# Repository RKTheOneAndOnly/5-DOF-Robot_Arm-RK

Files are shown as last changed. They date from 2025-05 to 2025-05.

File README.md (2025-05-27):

# 🤖 Kai (ಕೈ): A 5 Degree of Freedom Robotic Arm

Welcome to **Kai (ಕೈ)** — my latest hobby project and a significant step forward in my robotics journey. Kai (ಕೈ), meaning "hand" in Kannada, is a 5-DOF robotic arm built as a natural progression from my 3DOF project. With improved dexterity, orientation control, and a modular design, this DIY robotic arm project explores robotics, control systems, and embedded programming.
<p align="center">
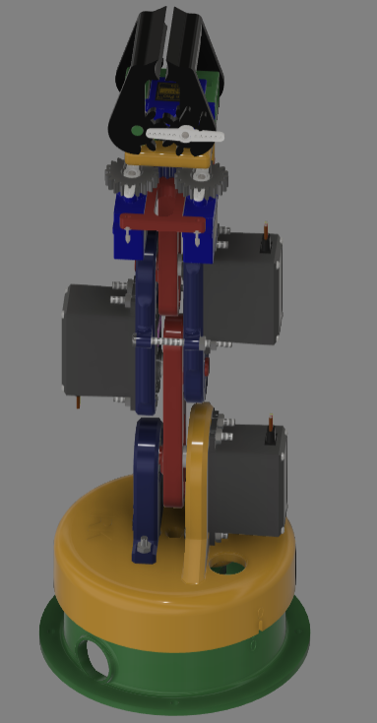
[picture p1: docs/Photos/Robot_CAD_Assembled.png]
Kai Robot CAD
    
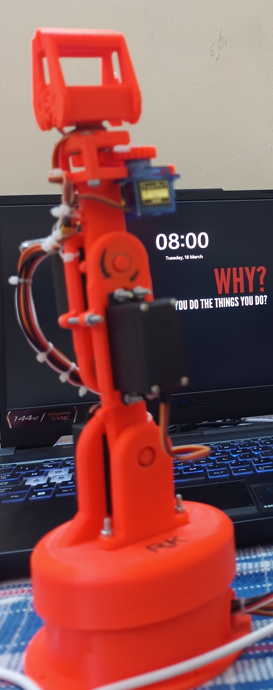
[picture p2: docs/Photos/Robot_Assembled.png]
Kai Robot Assembled
    
</p>

## 🔁 Previous Version: 3DOF Arm (V01)

Before building Kai (5DOF), I developed a 3DOF robotic arm as a foundational project. You can check it out here:

🔗 [Robotics-Arm-Project-V01](https://github.com/RKTheOneAndOnly/Robotics-Arm-Project-V01)

This earlier version helped me explore servo control, basic kinematics, and get hands-on with 3D printing and embedded design.

---
## Table of Contents

1. [Introduction](#1-introduction)
2. [Components Used](#2-components-used)
3. [Assembly Instructions](#3-assembly-instructions)
4. [Wiring Diagram](#4-wiring-diagram)
5. [Code Overview](#5-code-overview)
6. [Robot Video](#6-robot-video)
7. [Future Plans](#7-future-plans)
8. [License](#8-license)
9. [Repository Structure](#9-repository-structure)
10. [Credits & Acknowledgements](#10-credits--acknowledgements)

---
## 1. Introduction

This project focuses on designing, assembling, and controlling a 5DOF robotic arm that is:
-  Fully 3D printable
-  Made using easily available components
-  Controlled via inverse kinematics (IK) using Python + IkPy
-  Powered by ESP32 & PlatformIO, with web-based remote control
-  Open-source for learners, hobbyists, and engineers

---
## 2. Components Used

A detailed Engineering Bill of Materials (EBOM) is provided [here (Excel)](docs/Bill_of_Materials-5_DOF_Robot.xlsx).

| Component | Quantity | Notes |
|---|---|---|
| MG995  Servos | 1 | High torque servo motors |
| MG996R Servos | 4 | High torque servo motors |
| ESP 32 | 1 | Main controller |
| PCA 9685 | 1 | Servo driver (I2C) |
| 5V Power Supply  | 1 | Power source for servos |
| 3D Printed Parts | ~10 | Provided in `/stl` folder  |
| Misc. Hardware | - | Screws, bearings, etc. |

---
##  3. Assembly Instructions

The robotic arm is composed of modular, 3D-printed PLA joints designed for ease of assembly. Printing parameters such as infill density are provided in the [Bill of Materials (BOM)](docs/Bill_of_Materials-5_DOF_Robot.xlsx).

> 📌 **Note**: The part names used in these instructions match the file names available in the [STL](./stl) folder.

Follow the steps below to assemble **Kai**:

---

### 1. **Base Setup**
Mount the base servo motor (`MG995`) into the `BASE` structure. Insert ball bearings into their respective housings to reduce rotational friction. The base includes cutouts to route wires neatly and prevent tangling during rotation.

---

### 2. **Rotary Base Assembly**
Attach the `ARM-1-MAIN` component to the `BASE`. Ensure the base servo is positioned at **90°**, and align the zero markers on both `BASE` and `ARM-1-MAIN` for proper orientation.

---

### 3. **Support Arm & Second Servo Installation**
Fix the support arm `ARM-1-AUX` onto `ARM-1-MAIN` using screws. This component provides structural support via its bearing housing. Mount the second MG995 servo into `ARM-1-AUX`.

---

### 4. **Attaching the First Arm**
Connect `ARM-2` to the second servo motor (`MG996R`). Ensure the servo is set to **90°** before coupling to maintain consistent mechanical zeroing. The `ARM-2` component includes a boss feature that rides on the bearing within `ARM-1-AUX` to enhance rigidity and stability of the robot.

---

### 5. **Assembling the Second Arm**
Join `ARM-3-1` and `ARM-3-2` using two servo motors (`MG996R`) and screws. These parts include bearing housings that support both `ARM-2` and the upcoming `ARM-4` assembly. Once assembled, connect the complete second arm (`ARM-3-1` and `ARM-3-2` with servos) to `ARM-2` as shown in the reference images.

---

### 6. **Wrist Mechanism & Third Arm**
Mount `ARM-4` to the end of the second arm (`ARM-3`). Attach **two SG-90 micro servos**, which jointly drive a gear mechanism responsible for **wrist rotation (5th DOF)**. The mechanism is supported by bearings and features a square drive shaft for the gripper interface.

---

### 7. **Gripper Installation**
Fix the 3D-printed gripper to the square shaft of the wrist gear mechanism using screws. The gripper is actuated by a single `SG-90` micro servo, enabling open-close functionality. Ensure proper alignment for smooth operation.

---

### Step-by-Step Assembly Images

| Step | Image |
|---|---|
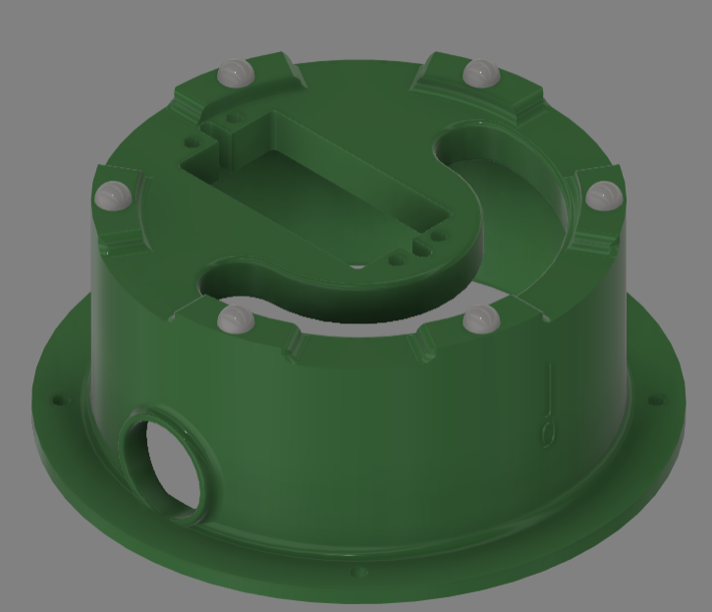
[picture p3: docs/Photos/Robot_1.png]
Base & Bearings
|1) **Base & Bearings** |  |
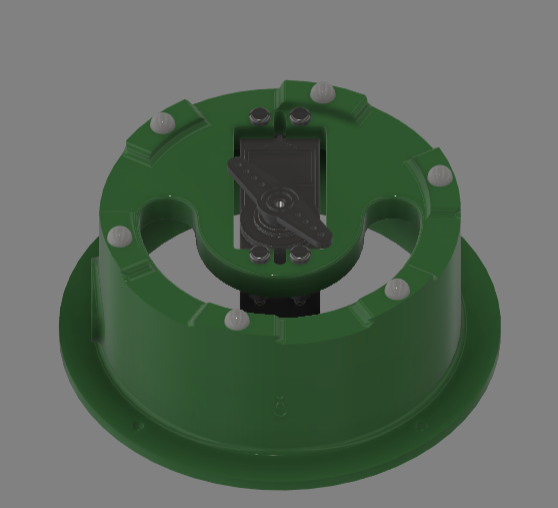
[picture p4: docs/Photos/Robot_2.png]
Base Motor Assembly
|2) **Base Motor Assembly**|  |
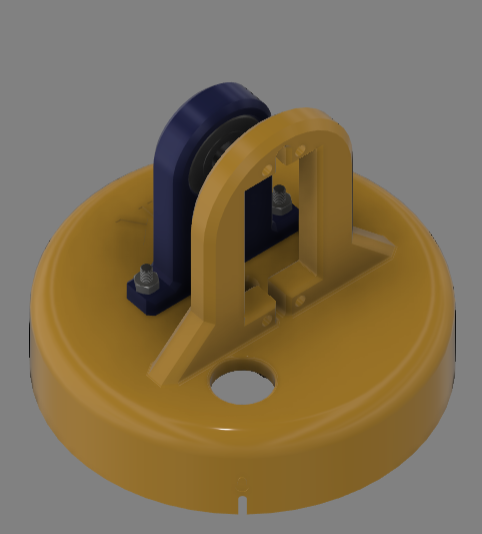
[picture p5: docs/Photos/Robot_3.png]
Arm 1 Assembly
|3) **Arm 1 Assembly** |  |
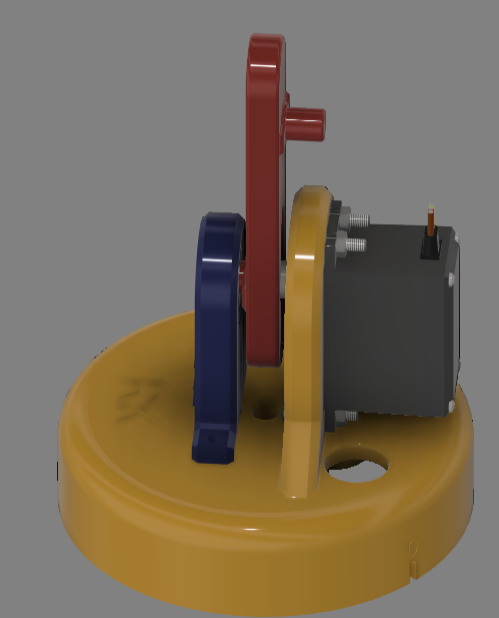
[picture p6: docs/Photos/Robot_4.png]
Arm 2 Assembly
|4) **Arm 2 Assembly** |  |
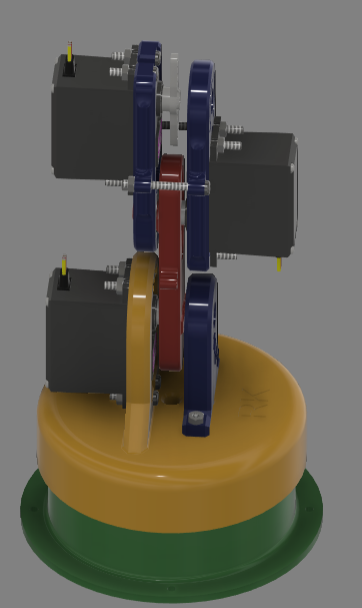
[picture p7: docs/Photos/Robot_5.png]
Arm 3 Assembly
|5) **Arm 3 Assembly** |  |
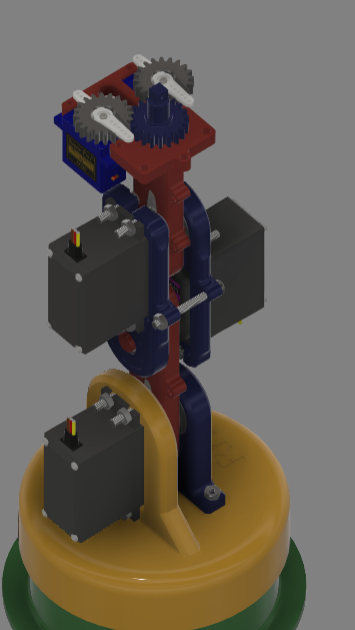
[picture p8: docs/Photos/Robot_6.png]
Wrist Gearing (a)
|6a)**Wrist Gearing (a)** |  |
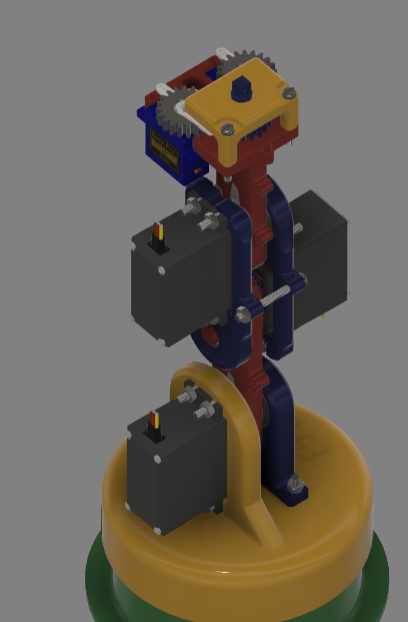
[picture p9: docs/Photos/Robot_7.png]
Wrist Gearing (b)
|6b) **Wrist Gearing (b)** |  |
|7) **Gripper & Final View** | Gripper & Final View |

> 🔧 **Tip**: Always set servos to **90°** before mechanical assembly to ensure consistent zeroing. This greatly simplifies motion planning and inverse kinematics calculations.

---

## 4. Wiring Diagram

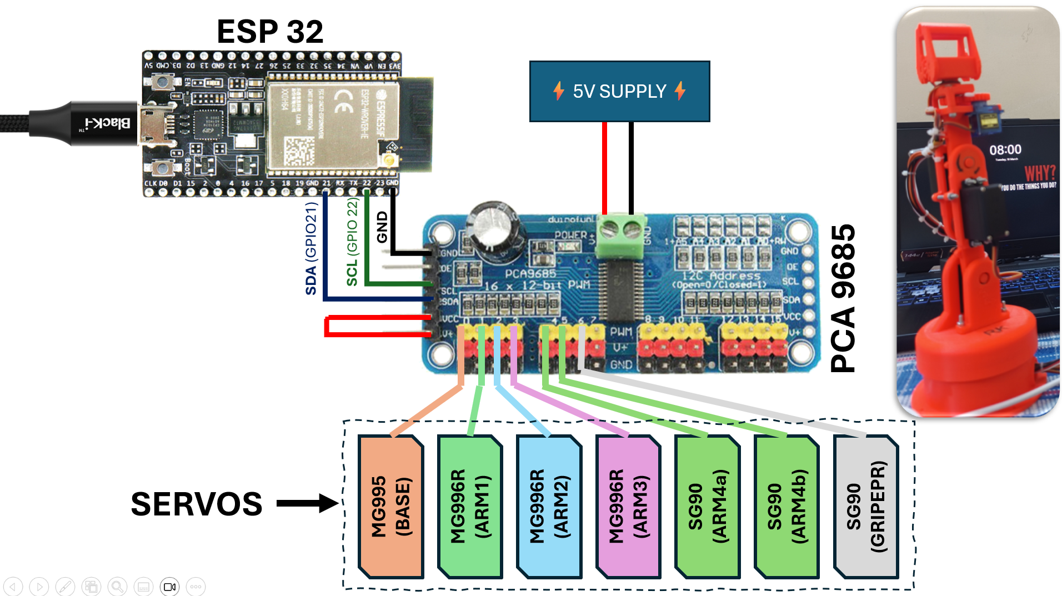
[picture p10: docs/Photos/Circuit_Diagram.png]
Wiring Diagram
  
*Wiring layout showing servo connections, PCA9685, ESP32 pinout, and external power supply.*

---

###  Key Wiring Details:

1. **Servo Connections**  
   A total of **7 servo motors** are used in this project. These are connected to a **PCA9685 16-channel PWM driver**, which is interfaced with the ESP32 via the **I2C** protocol.

2. **Microcontroller Interface**  
   The **ESP32** handles communication and control. I2C lines (SDA and SCL) from the ESP32 are connected to the corresponding inputs on the PCA9685.

3. **Power Supply**  
   An **external 5V power supply** is used to power the servos. Ensure that the **ground (GND)** of the power supply is **shared** with both the ESP32 and the PCA9685 module.

---

##  5. Code Overview

This project is powered by a combination of embedded C++ (via PlatformIO) and Python scripts, enabling high-level control, real-time kinematics solving, and remote web-based interfacing.

###  Inverse Kinematics Solver (Python)

- **Library Used**: [IkPy](https://github.com/Phylliade/ikpy)  
- **URDF Model**: The robot's kinematics are defined using a custom **URDF file**.
- **Functionality**:  
   - Accepts Cartesian goal position (x, y, z, orientation).
   - Solves inverse kinematics using the robot's URDF.
   - Outputs an array of 7 servo angles, ready to be sent to the microcontroller.

> 📁 Code Path: [`/code/src/Inverse_Kinematics_Controller.py`](./code/src/Inverse_Kinematics_Controller.py)

> 📁 URDF Path: [`/code/URDF_FIVE_DOF.urdf`](./code/URDF_FIVE_DOF.urdf)

---

### Web-based Remote Controller

The robot can be controlled manually using a web-based user interface hosted by a **Python Flask** server. This controller provides an intuitive and responsive way to articulate **Kai** in real-time without needing any complex tools.

- **Framework**: Python Flask  
- **Functionality**:
   - Hosts a local webpage with slider-based and button-based controls.
   - Sends real-time position and orientation inputs from the browser to the backend.
   - The backend converts these inputs to joint angles and sends them to the ESP32 for actuation.

> 📁 Code Path: [`/code/src/Online_Controller.py`](./code/src/Online_Controller.py)

The interface is designed to allow smooth and user-friendly manipulation of the robot. A preview of the controller is shown below:

<p align="center">
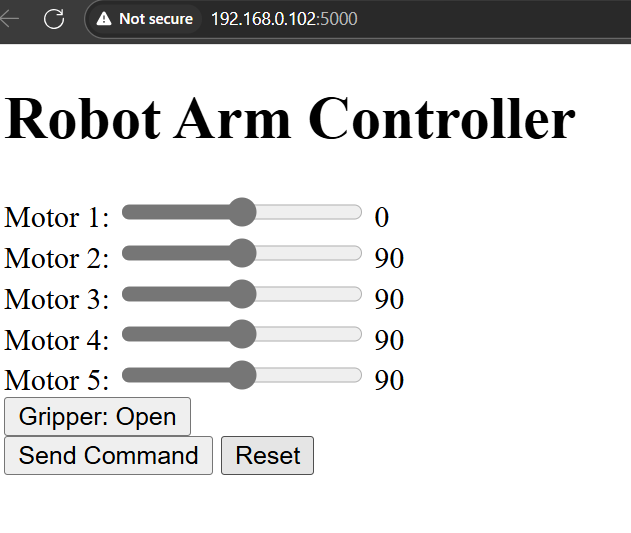
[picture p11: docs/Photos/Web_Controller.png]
Web Controller Interface
  
</p>

---
## 6. Robot Video

Here’s a glimpse of **Kai – the 5DOF Robotic Arm** in action!

The robot performs real-time pick-and-place tasks and orientation-based manipulation using servo-driven joints controlled via a inverse kinematics controller. The video showcases the robot arm demonstrating smooth motion control, coordinated joint movement, and precise end-effector positioning. 

This demonstration highlights Kai’s capabilities in workspace articulation, grip control, and stable motion handling — all built using affordable components and open-source tools.
Here are some demonstration videos of Kai (ಕೈ) in action:

> To watch demonstration videos of Kai (ಕೈ), please use the direct links below:

- [Video 1 – Orientation Control Demo](docs/Videos/Vid_1.mp4)
- [Video 2 – Pick and Place Demo](docs/Videos/Vid_2.mp4)

## 7. Future Plans

- Integrate camera for visual pick-and-place
- Full ROS2 implementation (RViz + MoveIt)

## 8. License

Licensed under the **GNU General Public License v3.0 (GPL-3.0)**.  
See the [LICENSE](./LICENSE) file for full details.

## 9. Repository Structure
```bash
5-DOF-Robotic-Arm-RK/
├── code/
│   ├── .pio/
│   ├── src/
│   │   ├── templates/
│   │   ├── Inverse_Kinematics_Controller.py
│   │   ├── Online_Controller.py
│   │   └── main.cpp
│   ├── URDF_FIVE_DOF.urdf
│   └── platformio.ini
├── docs/
│   ├── Photos/
│   ├── Videos/
│   ├── Bill_of_Materials-5_DOF_Robot.xlsx
│   └── robot_arm.yaml
├── stl/
├── LICENSE
└── README.md

```
## 10. Credits & Acknowledgements

Special thanks to:

- [IkPy](https://github.com/Phylliade/ikpy) – for providing an easy-to-use inverse kinematics library.
- [PlatformIO](https://platformio.org/) – for simplifying embedded development and dependency management.
- The open-source robotics community – for the abundance of shared knowledge, tools, and inspiration.

> *Crafted with ❤️, driven by curiosity, and fueled by innovation.*

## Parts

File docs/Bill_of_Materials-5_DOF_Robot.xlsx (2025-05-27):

Component List
Sl.No | Component | Quantity
1 | MG995 - Servo | 1
2 | MG996R - Servo | 3
3 | PCA9685 - Servo Driver I2C | 1
4 | SG 90 | 3
5 | 5V 5A SMPS Power Supply | 1
6 | M3 x 0.5 x 16 Pan Head Screw | 18
7 | M3 x 0.5 x 25 Pan Head Screw | 2
8 | M3 x 0.5 x 30 Pan Head Screw | 2
9 | M2 x 0.4 x 12 Pan Head Screw | 1
10 | Hex Nut M3 x 0.5 | 22
11 | Hex Nut M2 x 0.4 | 2
12 | Bearing 608ZZ | 4
13 | ESP 32 Dev Kit | 1
3D Printed Parts
Sl.no | Component | Infill % | Quantity
1 | BASE | 40 | 1
2 | ARM-1-MAIN | 60 | 1
3 | ARM-1-AUX | 60 | 1
4 | ARM-2 | 70 | 1
5 | ARM-3-1 | 60 | 1
6 | ARM-3-2 | 60 | 1
7 | ARM-4 | 60 | 1
8 | GEAR-SG-90-1 | 80 | 1
9 | GEAR-SG-90-2 | 80 | 1
10 | ARM-5-GEAR | 80 | 1
11 | ARM-5-HOLDER | 30 | 1
12 | GRIPPER-BASE | 70 | 1
13 | GRIPPER-ARM-LEFT | 80 | 1
14 | GRIPPER-ARM-RIGHT | 80 | 1
15 | Enclosure | 30 | 1

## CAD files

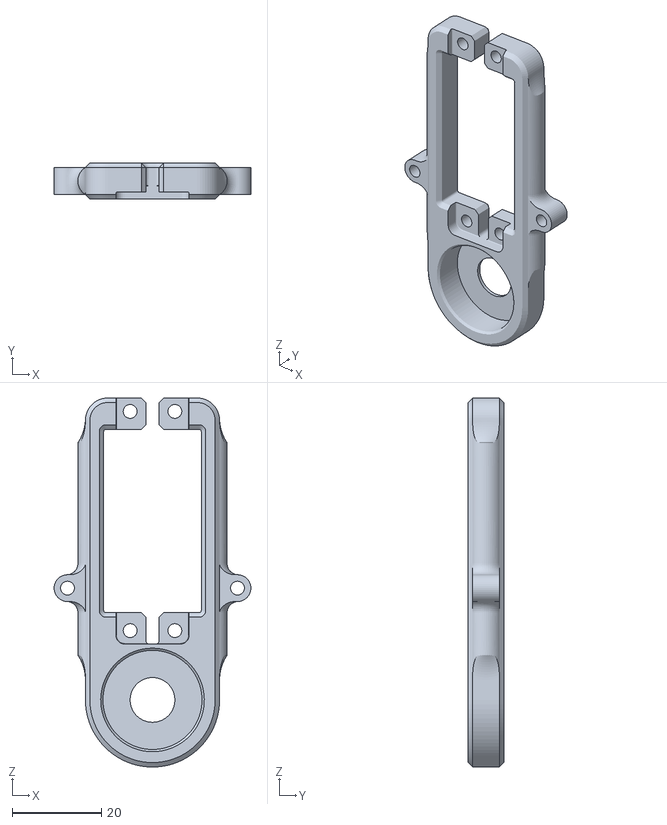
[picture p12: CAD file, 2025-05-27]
stl/ARM-3-2.stl
44.0 x 8.00 x 82.5

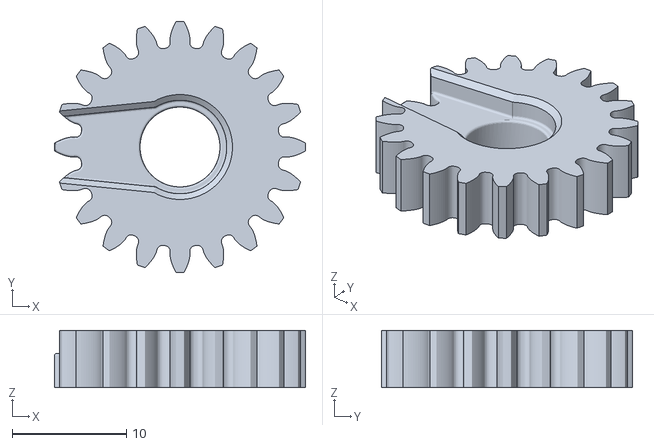
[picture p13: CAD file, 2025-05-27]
stl/GEAR-SG-90-1.stl
22.0 x 22.0 x 5.00

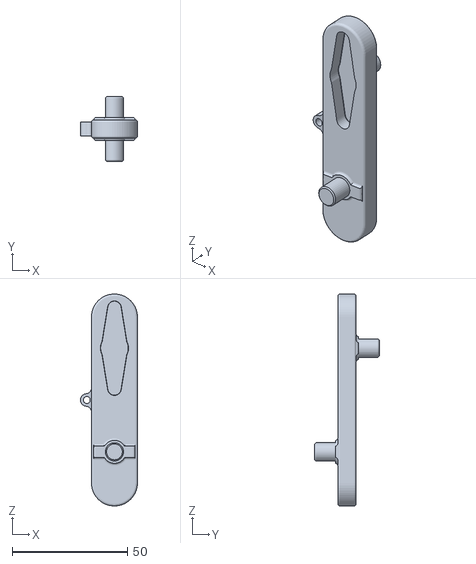
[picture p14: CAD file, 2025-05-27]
stl/ARM-2.stl
24.7 x 28.0 x 92.0

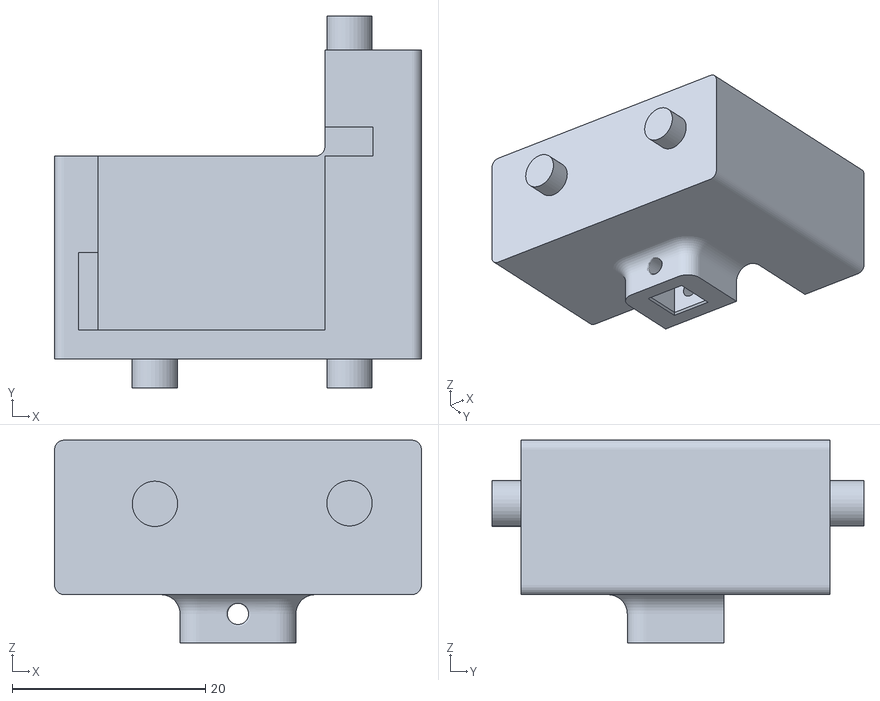
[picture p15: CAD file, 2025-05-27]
stl/GRIPPER-BASE.stl
38.0 x 38.5 x 21.0

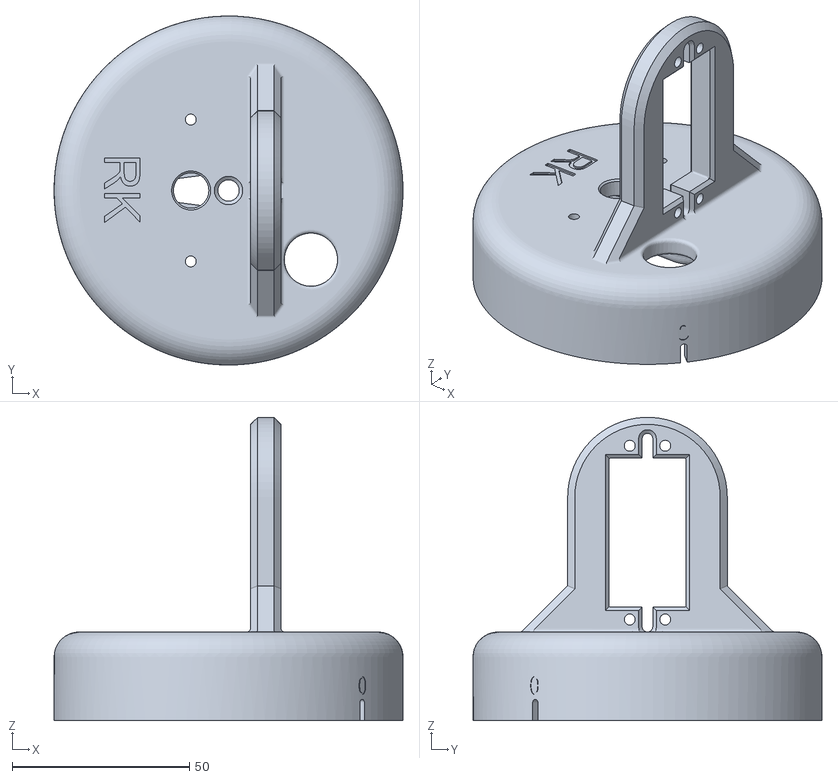
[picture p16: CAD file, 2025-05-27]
stl/ARM-1.stl
98.4 x 98.4 x 85.5

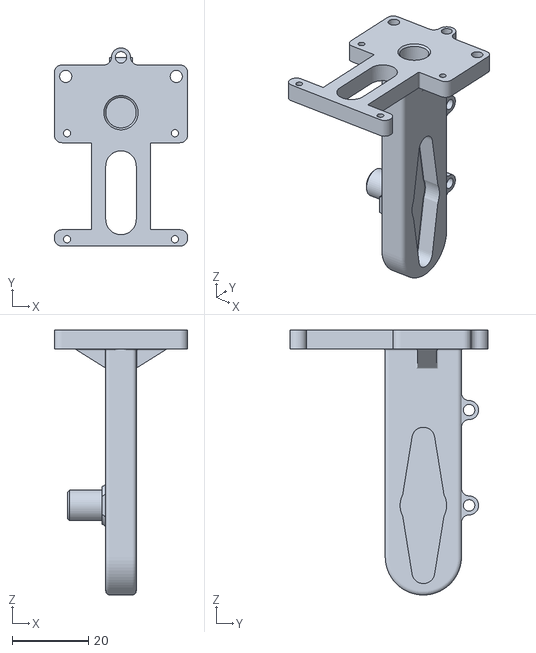
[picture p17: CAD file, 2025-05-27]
stl/ARM-4.stl
35.0 x 52.0 x 69.5

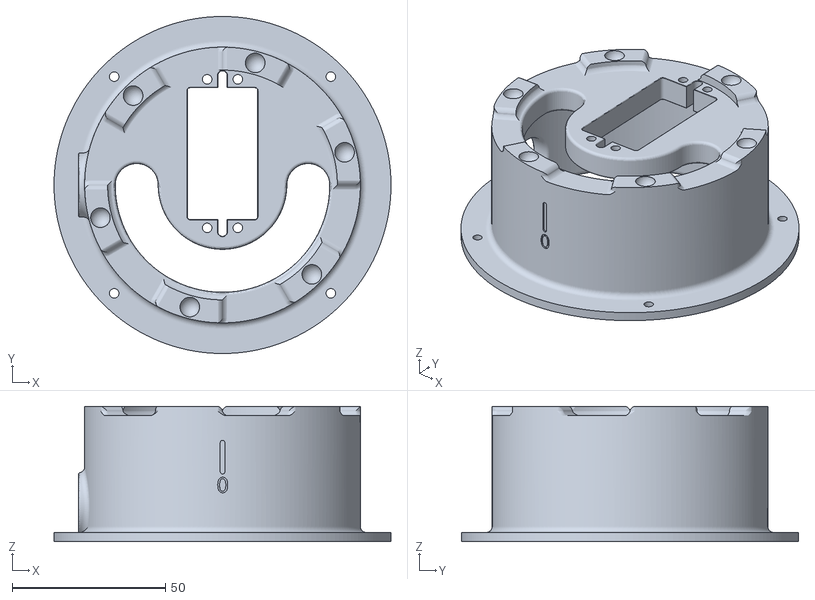
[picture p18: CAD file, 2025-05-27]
stl/BASE.stl
110.0 x 110.0 x 44.2

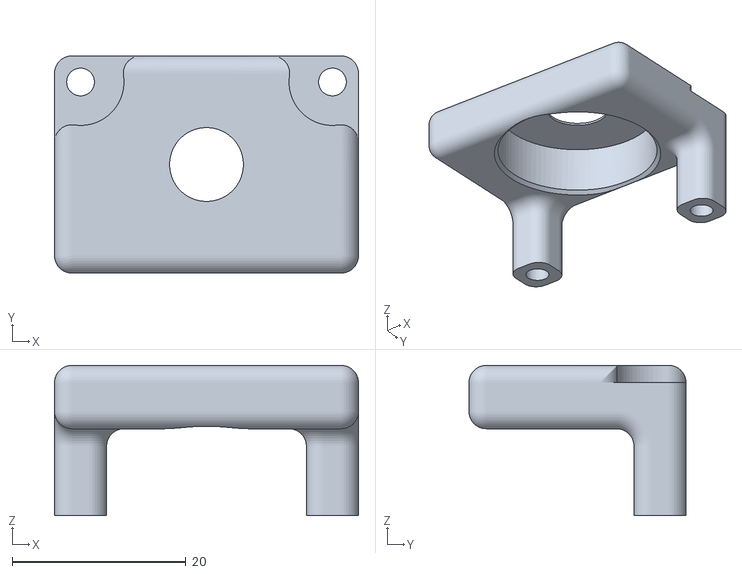
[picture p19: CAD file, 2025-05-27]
stl/ARM-5-HOLDER.stl
35.0 x 25.0 x 17.3

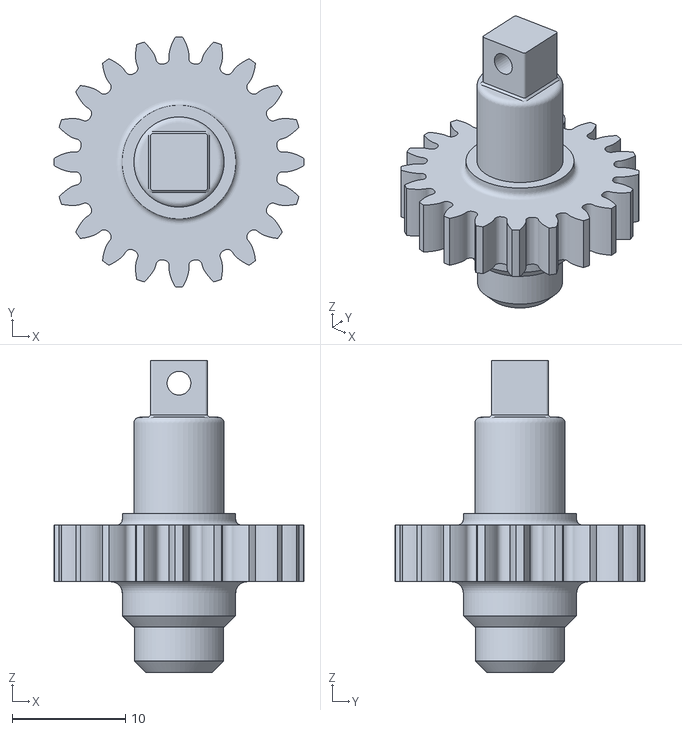
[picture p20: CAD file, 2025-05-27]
stl/ARM-5-GEAR.stl
22.0 x 22.0 x 27.5

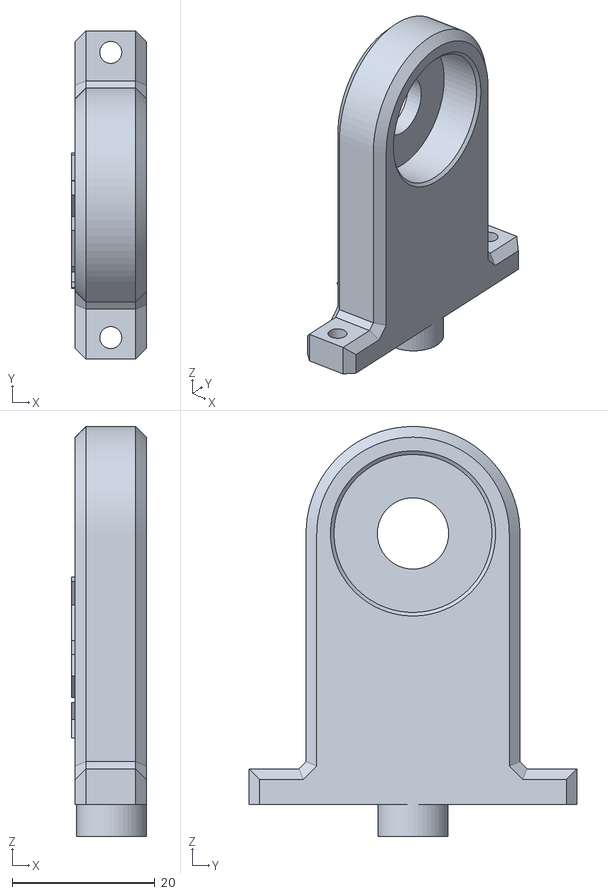
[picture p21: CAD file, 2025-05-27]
stl/ARM-1-AUX.stl
10.5 x 46.0 x 57.5

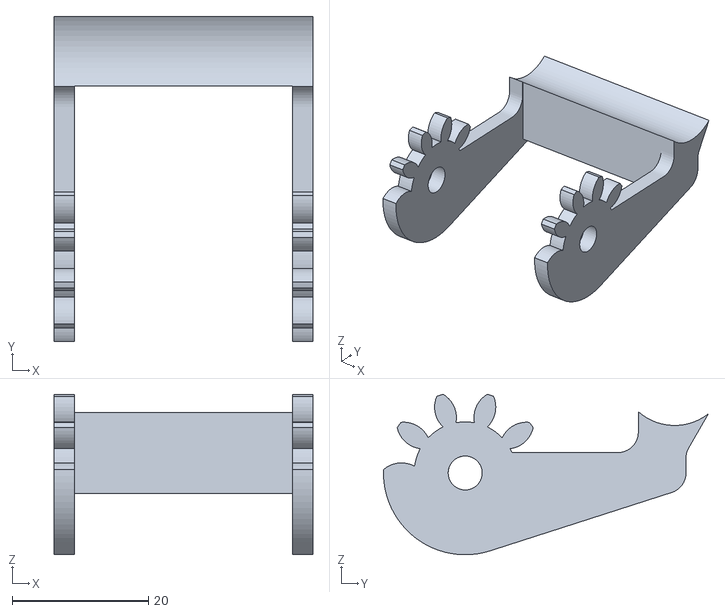
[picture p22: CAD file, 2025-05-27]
stl/GRIPPER-ARM-RIGHT.stl
38.0 x 47.7 x 23.6

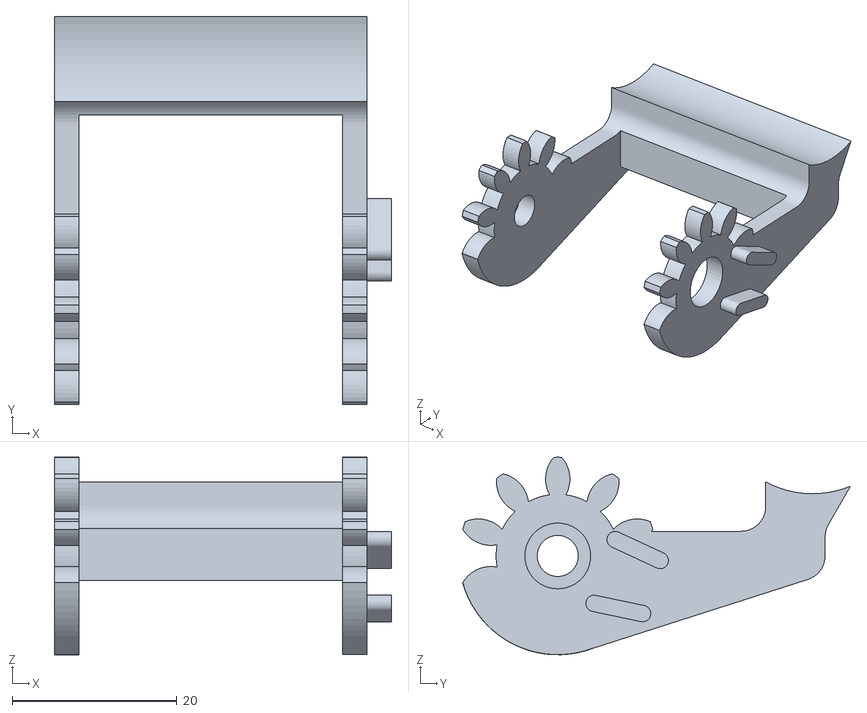
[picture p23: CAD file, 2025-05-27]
stl/GRIPPER-ARM-LEFT.stl
41.0 x 47.2 x 24.0

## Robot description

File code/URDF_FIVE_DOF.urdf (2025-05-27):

<?xml version="1.0"?>
<robot name="5DOF_Robot_By_Rohith_Kini_T">

<!-- Base Link -->
<link name="base_link">
		<visual>
		    <origin xyz="0 0 22.5" rpy="0 0 0"/>
			<geometry>
				<cylinder length="45" radius="50"/>
			</geometry>
		</visual>	
	</link>

<link name="Base_Rotary">
  <visual>
    <geometry>
      <box size="50 50 45" />
    </geometry>
  </visual>	
</link>
    
<joint name="Base_Joint" type="revolute">
  <parent link="base_link"/>
  <child link="Base_Rotary"/>
  <origin xyz="0 0 67.5" rpy="0 0 0" />
  <axis xyz="0 0 1"/>
  <limit lower="-1.571" upper="1.571"/>
</joint>

<link name="Arm1">
  <visual>
  <origin xyz="0 0 22.5" rpy="0 0 0"/>
    <geometry>
      <cylinder length="45" radius="15"/>
    </geometry>
  </visual>
</link>

<joint name="Arm1_Rotary" type="revolute">
  <parent link="Base_Rotary"/>
  <child link="Arm1"/>
  <origin xyz="0 0 22.5" rpy="0 0 0"/>
  <axis xyz="1 0 0"/>
  <limit lower="-1.571" upper="1.571"/>
</joint>

<link name="Arm2">
  <visual>
  <origin xyz="0 0 25" rpy="0 0 0"/>
    <geometry>
      <cylinder length="50" radius="10"/>
    </geometry>
  </visual>
</link>

<joint name="Arm2_Rotary" type="revolute">
  <parent link="Arm1"/>
  <child link="Arm2"/>
  <origin xyz="0 0 45" rpy="0 0 0"/>
  <axis xyz="1 0 0"/>
  <limit lower="-1.571" upper="1.571"/>
</joint>

<link name="Arm3">
  <visual>
  <origin xyz="0 0 23" rpy="0 0 0"/>
    <geometry>
      <cylinder length="46" radius="8"/>
    </geometry>
  </visual>
</link>

<joint name="Arm3_Rotary" type="revolute">
  <parent link="Arm2"/>
  <child link="Arm3"/>
  <origin xyz="0 0 50" rpy="0 0 0"/>
  <axis xyz="1 0 0"/>
  <limit lower="-1.571" upper="1.571"/>
</joint>

<link name="Arm4">
  <visual>
  <origin xyz="0 0 33.85" rpy="0 0 0"/>
    <geometry>
      <box size = "10 10 68.7"/>
    </geometry>
  </visual>
</link>

<joint name="Arm4_Rotary" type="revolute">
  <parent link="Arm3"/>
  <child link="Arm4"/>
  <origin xyz="0 0 46" rpy="0 0 0"/>
  <axis xyz="0 0 1"/>
  <limit lower="-1.571" upper="1.571"/>
</joint>

<link name="Gripper">
  <visual>
  <origin xyz="0 0 -10" rpy="0 0 0"/>
    <geometry>
      <box size = "20 20 20"/>
    </geometry>
  </visual>
</link>

<joint name ="Gripper" type="fixed">
  <parent link="Arm4"/>
  <child link="Gripper"/>
  <origin xyz="0 0 68.7" rpy="0 0 0"/>
</joint>

</robot>

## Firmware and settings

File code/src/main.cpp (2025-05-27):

#include <arduino.h>
#include <Adafruit_PWMServoDriver.h>
#include <Wire.h>
#include <SPI.h>

const int SERVO_1 = 0;  // Base Rotation
const int SERVO_2 = 1;  // Arm 1 Rotation
const int SERVO_3 = 2;  // Arm 2 Rotation
const int SERVO_4 = 3;  // Arm 3 Rotation
const int SERVO_5a = 4; // Arm 4 Rotation a
const int SERVO_5b = 5; // Arm 4 Rotation b
const int SERVO_6 = 6;  // Gripper

const int SERVO_1_MIN = 115; // Min Pulse MG 995
const int SERVO_1_MAX = 580; // Max Pulse MG 995
const int SERVO_2_MIN = 120; // Min Pulse MG 996R
const int SERVO_2_MAX = 560; // Max Pulse MG 996R 
const int SERVO_3_MIN = 120; // Min Pulse MG 996R
const int SERVO_3_MAX = 560; // Max Pulse MG 996R
const int SERVO_4_MIN = 120; // Min Pulse MG 996R
const int SERVO_4_MAX = 560; // Max Pulse MG 996R
const int SERVO_5_MIN = 100; // Min Pulse SG90 Tower Pro
const int SERVO_5_MAX = 570; // Max Pulse SG90 Tower Pro
const int SERVO_6_MIN = 100; // Min Pulse SG90 Tower Pro
const int SERVO_6_MAX = 570; // Max Pulse SG90 Tower Pro

const int SERVO_1_MIN_ANGLE = 0; // Min Anglle for Base Rotation
const int SERVO_1_MAX_ANGLE = 180; // Max Angle for Base Rotation
const int SERVO_2_MIN_ANGLE = 0; // Min Angle for Arm 1 Rotation
const int SERVO_2_MAX_ANGLE = 180; // Max Angle for Arm 1 Rotation
const int SERVO_3_MIN_ANGLE = 0; // Min Angle for Arm 2 Rotation
const int SERVO_3_MAX_ANGLE = 180; // Max Angle for Arm 2 Rotation
const int SERVO_4_MIN_ANGLE = 0; // Min Angle for Arm 3 Rotation
const int SERVO_4_MAX_ANGLE = 180; // Max Angle for Arm 3 Rotation
const int SERVO_5_MIN_ANGLE = 0; // Min Angle for Arm 4 Rotation
const int SERVO_5_MAX_ANGLE = 180; // Max Angle for Arm 4 Rotation
const int SERVO_6_MIN_ANGLE = 135; // Min Angle for Gripper
const int SERVO_6_MAX_ANGLE = 175; // Max Angle for Gripper

// Parking Positions for Servos
const int SERVO_1_PARK = 90; // Base Rotation
const int SERVO_2_PARK = 90; // Arm 1 Rotation
const int SERVO_3_PARK = 90; // Arm 2 Rotation
const int SERVO_4_PARK = 90; // Arm 3 Rotation
const int SERVO_5a_PARK = 90; // Arm 4 Rotation
const int SERVO_5b_PARK = SERVO_5a_PARK; // Arm 4 Rotation
const int SERVO_6_PARK = 180; // Gripper

// Converting Angle to motor pulses
const int SERVO_1_MIN_PULSE = map(SERVO_1_MIN_ANGLE, 0, 180, SERVO_1_MIN, SERVO_1_MAX);
const int SERVO_1_MAX_PULSE = map(SERVO_1_MAX_ANGLE, 0, 180, SERVO_1_MIN, SERVO_1_MAX);
const int SERVO_2_MIN_PULSE = map(SERVO_2_MIN_ANGLE, 0, 180, SERVO_2_MIN, SERVO_2_MAX);
const int SERVO_2_MAX_PULSE = map(SERVO_2_MAX_ANGLE, 0, 180, SERVO_2_MIN, SERVO_2_MAX);
const int SERVO_3_MIN_PULSE = map(SERVO_3_MIN_ANGLE, 0, 180, SERVO_3_MIN, SERVO_3_MAX);
const int SERVO_3_MAX_PULSE = map(SERVO_3_MAX_ANGLE, 0, 180, SERVO_3_MIN, SERVO_3_MAX);
const int SERVO_4_MIN_PULSE = map(SERVO_4_MIN_ANGLE, 0, 180, SERVO_4_MIN, SERVO_4_MAX);
const int SERVO_4_MAX_PULSE = map(SERVO_4_MAX_ANGLE, 0, 180, SERVO_4_MIN, SERVO_4_MAX);
const int SERVO_5_MIN_PULSE = map(SERVO_5_MIN_ANGLE, 0, 180, SERVO_5_MIN, SERVO_5_MAX);
const int SERVO_5_MAX_PULSE = map(SERVO_5_MAX_ANGLE, 0, 180, SERVO_5_MIN, SERVO_5_MAX);
const int SERVO_6_MIN_PULSE = map(SERVO_6_MIN_ANGLE, 0, 180, SERVO_6_MIN, SERVO_6_MAX);
const int SERVO_6_MAX_PULSE = map(SERVO_6_MAX_ANGLE, 0, 180, SERVO_6_MIN, SERVO_6_MAX);

const int SERVO_1_PARK_PULSE = map(SERVO_1_PARK, 0, 180, SERVO_1_MIN, SERVO_1_MAX);
const int SERVO_2_PARK_PULSE = map(SERVO_2_PARK, 0, 180, SERVO_2_MIN, SERVO_2_MAX);
const int SERVO_3_PARK_PULSE = map(SERVO_3_PARK, 0, 180, SERVO_3_MIN, SERVO_3_MAX);
const int SERVO_4_PARK_PULSE = map(SERVO_4_PARK, 0, 180, SERVO_4_MIN, SERVO_4_MAX);
const int SERVO_5a_PARK_PULSE = map(SERVO_5a_PARK, 0, 180, SERVO_5_MIN, SERVO_5_MAX);
const int SERVO_5b_PARK_PULSE = map(SERVO_5b_PARK, 0, 180, SERVO_5_MIN, SERVO_5_MAX);
const int SERVO_6_PARK_PULSE = map(SERVO_6_PARK, 0, 180, SERVO_6_MIN, SERVO_6_MAX);

int SERVO_1_POS = SERVO_1_PARK_PULSE;
int SERVO_2_POS = SERVO_2_PARK_PULSE;
int SERVO_3_POS = SERVO_3_PARK_PULSE;
int SERVO_4_POS = SERVO_4_PARK_PULSE;
int SERVO_5a_POS = SERVO_5a_PARK_PULSE;
int SERVO_5b_POS = SERVO_5b_PARK_PULSE;
int SERVO_6_POS = SERVO_6_PARK_PULSE;

//============================================================================================
// Defining the PWM Driver
Adafruit_PWMServoDriver pwm = Adafruit_PWMServoDriver(); // Uses Slave Address 0x40

void setup() {
    Serial.begin(115200);
    pwm.begin();
    pwm.setPWMFreq(60); // Analog servos run at ~60 Hz updates
    Serial.println("Servos Configured and Ready to Rock and Roll......");
    Serial.println("Awaiting Orders");    
}

void IRAM_ATTR Move_Robot(float Angle1, float Angle2, float Angle3, float Angle4, float Angle5, float GripperState) {
  // Angle1 - Base Rotation (90 Degree of motor is set as zero in actual)
  // Angle2 - Arm 1 Rotation
  // Angle3 - Arm 2 Rotation
  // Angle4 - Arm 3 Rotation
  // Angle5 - Arm 4 Rotation - Gripper Orientation Control
  // GripperState - Gripper Open/Close (0 or 1)

  
  // Adjusting the zero position
  Angle1 += 90;
  Angle1 = constrain(Angle1, SERVO_1_MIN_ANGLE, SERVO_1_MAX_ANGLE); // Constrain to the set limits
  Angle2 = constrain(Angle2, SERVO_2_MIN_ANGLE, SERVO_2_MAX_ANGLE); // Constrain to the set limits
  Angle3 = constrain(Angle3, SERVO_3_MIN_ANGLE, SERVO_3_MAX_ANGLE); // Constrain to the set limits
  Angle4 = constrain(Angle4, SERVO_4_MIN_ANGLE, SERVO_4_MAX_ANGLE); // Constrain to the set limits
  Angle5 = constrain(Angle5, SERVO_5_MIN_ANGLE, SERVO_5_MAX_ANGLE); // Constrain to the set limits
  GripperState = constrain(GripperState, 0, 1); // Constrain to the set limits

  int Target_Pulse_1 = map(Angle1, 0, 180, SERVO_1_MIN_PULSE, SERVO_1_MAX_PULSE); // Pulse Signal for Base Rotation
  int Target_Pulse_2 = map(Angle2, 0, 180, SERVO_2_MIN_PULSE, SERVO_2_MAX_PULSE); // Pulse Signal for Arm 1 Rotation
  int Target_Pulse_3 = map(Angle3, 0, 180, SERVO_3_MIN_PULSE, SERVO_3_MAX_PULSE); // Pulse Signal for Arm 2 Rotation
  int Target_Pulse_4 = map(Angle4, 0, 180, SERVO_4_MIN_PULSE, SERVO_4_MAX_PULSE); // Pulse Signal for Arm 3 Rotation
  int Target_Pulse_5 = map(Angle5, 0, 180, SERVO_5_MIN_PULSE, SERVO_5_MAX_PULSE); // Pulse Signal for Arm 4 Rotation
  int Target_Pulse_6 = GripperState == 1 ? SERVO_6_MAX_PULSE : SERVO_6_MIN_PULSE; // Pulse Signal for Gripper Open/Close
  pwm.setPWM(SERVO_5a, 0, Target_Pulse_5);
  pwm.setPWM(SERVO_5b, 0, Target_Pulse_5);
  pwm.setPWM(SERVO_6, 0, Target_Pulse_6);

  // Get current positions
  int start_pulse_1 = SERVO_1_POS;
  int start_pulse_2 = SERVO_2_POS;
  int start_pulse_3 = SERVO_3_POS;
  int start_pulse_4 = SERVO_4_POS;
  int start_pulse_5a = SERVO_5a_POS;
  int start_pulse_5b = SERVO_5b_POS;
  int start_pulse_6 = SERVO_6_POS;

  // Get current positions
  SERVO_5a_POS = Target_Pulse_5;
  SERVO_5b_POS = Target_Pulse_5;
  SERVO_6_POS = Target_Pulse_6;

  // Calculate deltas
  int delta1 = Target_Pulse_1 - start_pulse_1;
  int delta2 = Target_Pulse_2 - start_pulse_2;
  int delta3 = Target_Pulse_3 - start_pulse_3;
  int delta4 = Target_Pulse_4 - start_pulse_4;

  // Find maximum absolute delta
  int max_diff = max(abs(delta1), max(abs(delta2), max(abs(delta3),abs(delta4))));

  if (max_diff == 0) {
    delay(500);
    Serial.println("");
    Serial.println("Done");
    return;
  }
// Motion parameters
const int step_delay = 3; //overall speed (ms per step)
  
// Smooth movement with acceleration/deceleration
  for (int i = 0; i <= max_diff; i++) {
    float t = (float)i / max_diff;
    // Smoothstep easing function (3t² - 2t³)
    float eased_t = t * t * (3.0 - 2.0 * t);

    // Calculate intermediate positions
    int current1 = start_pulse_1 + round(delta1 * eased_t);
    int current2 = start_pulse_2 + round(delta2 * eased_t);
    int current3 = start_pulse_3 + round(delta3 * eased_t);
    int current4 = start_pulse_4 + round(delta4 * eased_t);

    // Update servo positions
    pwm.setPWM(SERVO_1, 0, current1);
    pwm.setPWM(SERVO_2, 0, current2);
    pwm.setPWM(SERVO_3, 0, current3);
    pwm.setPWM(SERVO_4, 0, current4);

    // Update global position trackers
    SERVO_1_POS = current1;
    SERVO_2_POS = current2;
    SERVO_3_POS = current3;
    SERVO_4_POS = current4;
    delay(step_delay);
  }
    Serial.println("");
    Serial.println("Done");
  }
  
  void loop() {
    //take user input with decimal places
    float Angle1, Angle2, Angle3, Angle4, Angle5;
    int GripperState;
    static String inputString = ""; 
    static bool inputComplete = false;

  while (Serial.available() > 0) {
    char incomingChar = Serial.read();

    if (incomingChar == '\n') {
      inputComplete = true;
      Serial.println("Enter the angles and gripper state separated by spaces : ");
      break;
    } else {
      inputString += incomingChar; 
    }
  }

    if (inputComplete) {
        inputString.trim();
        Serial.print(inputString);
        if (inputString.length() > 0) {
            int firstSpaceIndex = inputString.indexOf(' ');
            int secondSpaceIndex = inputString.indexOf(' ', firstSpaceIndex + 1);
            int thirdSpaceIndex = inputString.indexOf(' ', secondSpaceIndex + 1);
            int fourthSpaceIndex = inputString.indexOf(' ', thirdSpaceIndex + 1);
            int fifthSpaceIndex = inputString.indexOf(' ', fourthSpaceIndex + 1);
            
            Angle1 = inputString.substring(0, firstSpaceIndex).toFloat();
            Angle2 = inputString.substring(firstSpaceIndex + 1, secondSpaceIndex).toFloat();
            Angle3 = inputString.substring(secondSpaceIndex + 1, thirdSpaceIndex).toFloat();
            Angle4 = inputString.substring(thirdSpaceIndex + 1, fourthSpaceIndex).toFloat();
            Angle5 = inputString.substring(fourthSpaceIndex + 1, fifthSpaceIndex).toFloat();
            GripperState = inputString.substring(fifthSpaceIndex + 1).toInt();
            
            Move_Robot(Angle1, Angle2, Angle3, Angle4, Angle5, GripperState);

            //print angles
            Serial.print("User Values : [");
            Serial.print(Angle1);
            Serial.print(" ");
            Serial.print(Angle2);
            Serial.print(" ");
            Serial.print(Angle3);
            Serial.print(" ");
            Serial.print(Angle4);
            Serial.print(" ");
            Serial.print(Angle5);
            Serial.print(" ");
            Serial.print(GripperState);
            Serial.println("]");
        }
    inputString = "";
    inputComplete = false;
    }
}

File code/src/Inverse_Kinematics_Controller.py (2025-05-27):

import serial
import time
import numpy as np
from ikpy.chain import Chain

Robot_Chain = Chain.from_urdf_file("URDF_FIVE_DOF.urdf",active_links_mask=[False, True, True, True, True, True, False])

ser = serial.Serial('COM6', 115200) 
time.sleep(2)
def wait_for_arduino():
    while True:
        if ser.in_waiting > 0:
            response = ser.readline().decode().strip()
            print(f"Received: {response}")
            if response == "Awaiting Orders":
                break

def send_command(angle1, angle2, angle3, angle4, angle5, gripper):
    command = f"{angle1} {angle2} {angle3} {angle4} {angle5} {gripper}\n"
    print(f"Sent: {command.strip()}")
    ser.write(command.encode())
    time.sleep(0.1)
    while True:
        if ser.in_waiting > 0:
            response = ser.readline().decode().strip()
            print(f"Received: {response}")
            if response == "Done":
                break

def get_user_input():
    while True:
        print("=======================================================================================")
        user_input = input("Enter target position (x y z Gripper_state) separated by spaces (q\Q to Quit): ")
        try:
            if user_input.strip().lower() == 'q':
                print("Exiting program.")
                if ser.is_open:
                    send_command(0, 90, 90, 90, 90, 1)  # Parks the Robot
                    print("Robot parked. Closing serial connection.")
                    ser.close()
                exit(0)
            parts = user_input.strip().split()
            x, y, z, gripper_state = map(float, parts)
            if not gripper_state.is_integer() or gripper_state not in [0, 1]:
                raise ValueError("Gripper state must be 0 (Open) or 1 (Close).")
            if not (-200 <= x <= 200 and -200 <= y <= 200 and 0 <= z <= 300):
                raise ValueError("Coordinates must be within realistic operational limits: x and y between -200 and 200, z between 0 and 300.")
            print(f"Target Position: x={x}, y={y}, z={z}, Gripper State: {'Open' if gripper_state == 0 else 'Closed'}")
            print("=======================================================================================")
            return [x, y, z, int(gripper_state)]
        except ValueError as ve:
            print(f"Error : {ve}")

if __name__ == "__main__":
    wait_for_arduino()

    while True:
        # Get target position from user input
        target_position = get_user_input()       # Contains [x, y, z, gripper_state]
        gripper_state = int(target_position[3])  # Gripper state (0 for closed, 1 for open)
        Target_Orientation = [0, 0, -1]          # Orientation (adjust as needed)

        # Compute inverse kinematics
        ik_results = Robot_Chain.inverse_kinematics(target_position[:3], Target_Orientation, orientation_mode="Y")
        joint_angles_deg = np.rad2deg(ik_results)

        # Map joint angles to motor angles (adjust based on your robot's configuration)
        Motor_Angle_Degrees = [0, 0, 0, 0, 0]
        Motor_Angle_Degrees[0] = joint_angles_deg[1]
        Motor_Angle_Degrees[1] = joint_angles_deg[2] + 90
        Motor_Angle_Degrees[2] = joint_angles_deg[3] + 90
        Motor_Angle_Degrees[3] = joint_angles_deg[4] + 90
        Motor_Angle_Degrees[4] = joint_angles_deg[5] + 90
        Motor_Angle_Degrees = np.round(Motor_Angle_Degrees, 1)

        # Display computed angles
        print("Computed Motor Angles (Degrees):")
        print(f"Motor 1 = {Motor_Angle_Degrees[0]} | Motor 2 = {Motor_Angle_Degrees[1]} | Motor 3 = {Motor_Angle_Degrees[2]} | Motor 4 = {Motor_Angle_Degrees[3]} | Motor 5 = {Motor_Angle_Degrees[4]};")
        print(f"Gripper State: {'Open' if gripper_state == 0 else 'Closed'}")
        print("=======================================================================================")

        # Wait for user confirmation to execute
        execute = input("Press 'e' to execute or any other key to recompute angles: ").strip().lower()
        if execute == 'e':
            send_command(Motor_Angle_Degrees[0], Motor_Angle_Degrees[1], Motor_Angle_Degrees[2], Motor_Angle_Degrees[3], Motor_Angle_Degrees[4], gripper_state)
            print("Command executed!")
        else:
            print("Angles recomputed. Enter a new target position.")
